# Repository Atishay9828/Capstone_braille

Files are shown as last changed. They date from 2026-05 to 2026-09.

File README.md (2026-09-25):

# Braillix

Braillix is a refreshable braille cell. It shows one braille character at a time,
and it changes that character on command. A single stepper motor moves all six
dots. The parts are 3D printed. The controller is an ESP32.

**Live mechanism simulator: https://mridulnegi2005.github.io/Capstone/**

The simulator runs the real cam profile. It reads the same numbers as the CAD
files. A motion that the printed cam cannot make is a motion the simulator cannot
show.

---

## Live demos

| Classroom frontend | Hardware mechanism |
|:--:|:--:|
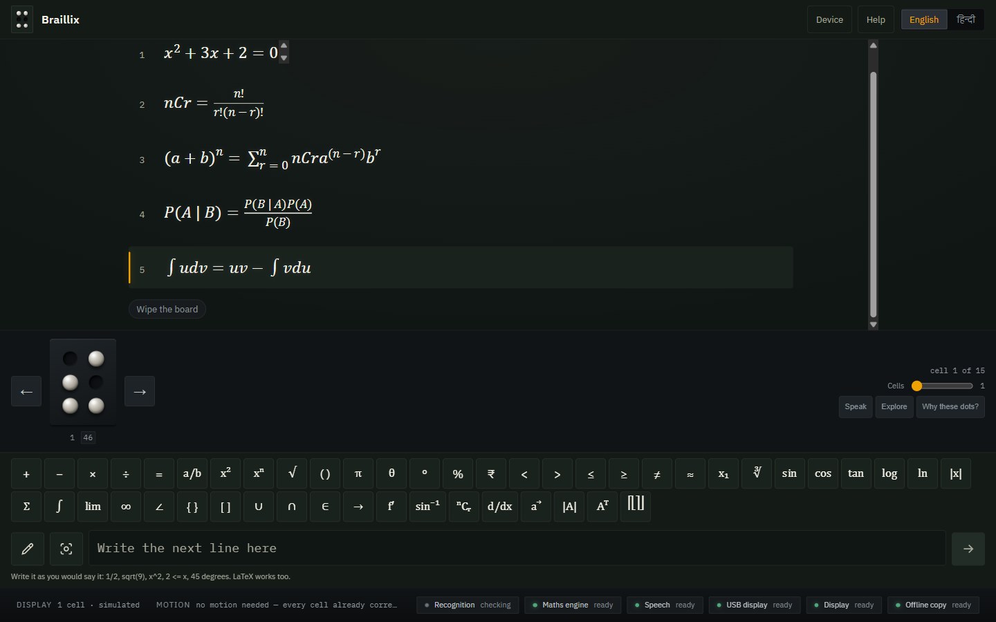
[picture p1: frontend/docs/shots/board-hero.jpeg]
Screenshot of the Braillix classroom frontend
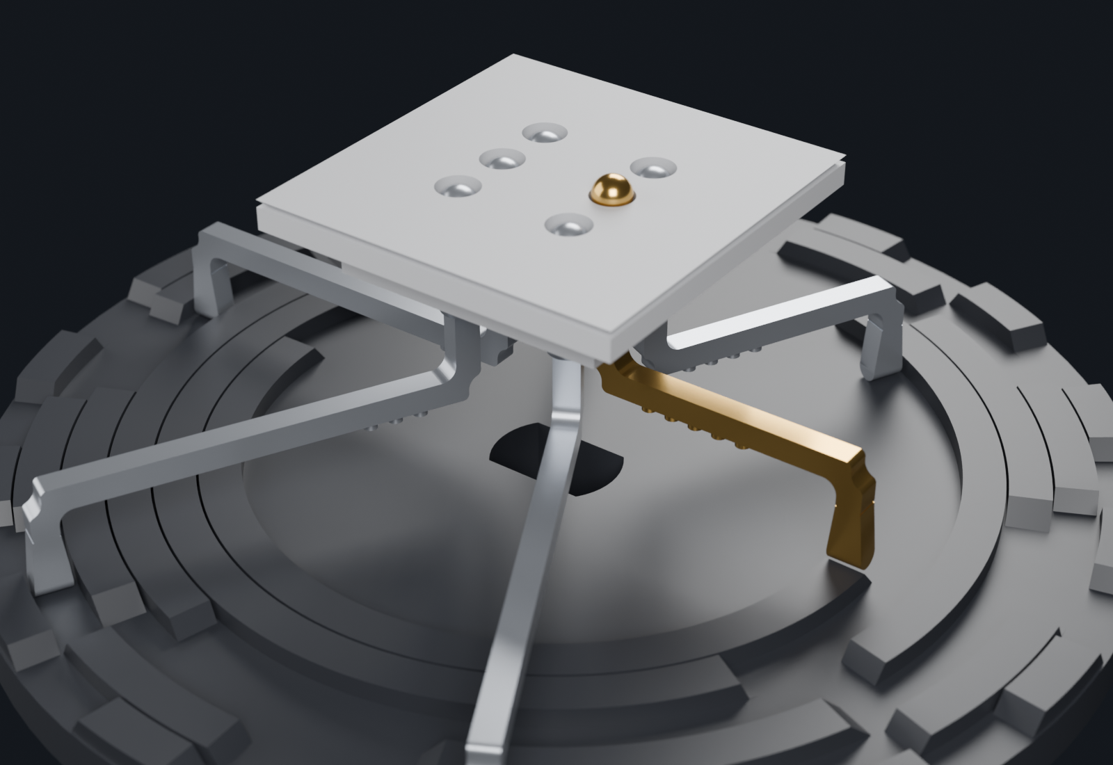
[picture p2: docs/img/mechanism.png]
3D render of the Braillix refreshable Braille cell mechanism
| [](https://braillix.vercel.app) | [](https://mridulnegi2005.github.io/Capstone/) |
| [Open the live classroom app](https://braillix.vercel.app) | [Open the live hardware simulator](https://mridulnegi2005.github.io/Capstone/) |

- **Backend API:** no public deployment is configured yet. Run it locally using the steps below;
  its interactive documentation is available at `http://localhost:8000/docs` while it is running.

The Vercel frontend and GitHub Pages simulator are separate deployments. The FastAPI service
currently runs locally and is not required by the frontend's main lesson flow.

## Software components

The software is split into a browser classroom app and a separately runnable Python API. Both
connect to the same Braillix goal—turning lesson content into Braille—but they do not currently
depend on each other for their main flows. The browser app performs its recognition and lesson
translation locally; the API exposes independent translation, OCR, and classroom-session
endpoints. The hardware and simulator live alongside them in this repository.

### Frontend classroom app (`frontend/`)

The React and TypeScript app provides a teacher-facing lesson blackboard. Teachers can type,
write, or photograph lesson content; inspect recognition and Braille readback; and send the
result to a simulator, a USB-connected pod, or Wi-Fi pods. English and Hindi text, mathematical
notation, speech, and multi-cell navigation are part of the browser app. Recognition and lesson
translation run on-device after the needed assets have been downloaded, so the basic lesson flow
does not require the Python API.

The frontend was imported with its commit history from
[SHV27/braillix](https://github.com/SHV27/braillix). It uses Node.js 20.19 or newer. To run it:

```bash
cd frontend
npm install
npm run fetch:model                 # one-time download of the math recognition model
node tools/fetch-tesseract-langs.mjs # one-time download of English and Hindi OCR data
npm run dev
```

Open the local URL printed by Vite (normally `http://localhost:5173`). For architecture,
feature details, optional pod simulation, and all frontend commands, see
[`frontend/README.md`](frontend/README.md) and [`frontend/ARCHITECTURE.md`](frontend/ARCHITECTURE.md).

### Backend API (`backend/`)

The Python service is built with FastAPI. It provides:

- Text and LaTeX mathematics translation to Braille, including converted cam-angle data.
- Image and PDF OCR endpoints for extracting lesson content and converting images to Braille.
- Classroom sessions with teacher and student WebSocket connections.
- A health endpoint and interactive API documentation.

The API creates its SQLite database (`braillix.db`) when it starts. Translation depends on the
system `liblouis` library and its tables. On Linux or macOS, the setup helper installs that
library, creates a virtual environment, and installs the Python dependencies:

```bash
bash scripts/setup.sh
source .venv/bin/activate
make dev
```

The service listens on `http://localhost:8000`; interactive documentation is at
[`/docs`](http://localhost:8000/docs). Main routes include `POST /translate`,
`POST /translate-math`, `POST /translate/cam-angles`, `POST /ocr/image`,
`POST /ocr/image-to-braille`, `POST /ocr/process-pdf`, `POST /classroom/sessions`, and the
`/classroom/teacher/{code}` and `/classroom/student/{code}` WebSocket routes. Starting without
`liblouis` is possible, but translation endpoints that need it report that the dependency is
unavailable. The setup helper currently supports Linux and macOS; on other systems install
`liblouis` and its tables manually before installing `requirements.txt` and running `make dev`.

### Hardware and simulator

The hardware path includes CAD, ESP32 firmware, the hardware abstraction layer, and the
mechanism simulator in `cad/`, `firmware/`, `hal/`, and `sim/`. Its original history is preserved
from [MridulNegi2005/Capstone](https://github.com/MridulNegi2005/Capstone). The browser app's
protocol and hardware setup are documented in [`frontend/docs/PROTOCOL.md`](frontend/docs/PROTOCOL.md)
and [`docs/`](docs/).

## What the device does

A braille character uses a cell of six dots. Each dot is up or down. Six dots give
64 different patterns. A reader identifies the character by touch.

Braillix raises and lowers those six dots on demand. A teacher sets a letter, and
a student reads it. The device then changes to the next letter.

Commercial refreshable braille displays cost between 2,000 and 6,000 US dollars.
They use piezoelectric actuators. Each dot needs its own actuator, and each
actuator is expensive. Braillix uses one motor and a shaped disc instead.

---

## How the mechanism works

The heart of the device is a **cam disc**. A cam is a shaped part that converts
rotation into linear movement.

### The disc

The disc carries six circular **tracks**. One track drives one dot. Each track has
high sections and low sections around its circumference.

The disc turns to 64 angular positions. Each position is one **slice**. Each slice
carries one of the 64 dot patterns.

### The follower

A **linkage** rests on each track. The linkage is a rigid crank. Its **foot** sits
on the track. Its other end carries the braille dot.

The mechanism

*The cam disc below, the six linkages above it, and the reading surface on top.
One linkage is gold. Its foot stands on a high section of its track, so its dot is
raised. The other five are down. The comb and the enclosure are left out of this
view.*

When the foot meets a high section, the linkage moves up. The dot rises above the
reading surface. When the foot meets a low section, the linkage moves down. The
dot becomes flush with the surface.

A return spring holds each linkage down against the disc.

### One motor for six dots

The six tracks turn together, because they are on one disc. One rotation of the
motor therefore sets all six dots at once. This removes the need for six
actuators.

The motor is a 28BYJ-48 stepper. It makes 4096 steps for each revolution. One
slice is 64 steps. The firmware turns the motor to the slice that holds the wanted
pattern.

### The guide

The foot rests on the disc. It does not clamp to it. A rotating disc therefore
drags the linkage sideways. A **comb** stops this. The comb is a fixed plate above
the disc. It has one closed pocket for each foot. The linkage slides up and down
in its pocket, and it cannot turn.

### Gray order

The slices do not carry the patterns in counting order. They carry them in **Gray
order**. In Gray order, two neighbour slices differ by exactly one bit. Only one
dot therefore moves for each step of the disc.

This gives two results. The dots do not flicker as much between letters. The motor
also lifts one dot at a time, not six, so it needs less torque.

The cam, the firmware and the simulator all share this order. All three must agree.

### Homing

A magnet sits in the underside of the disc. A hall sensor sits in the base plate
below it. The controller turns the disc until the sensor finds the magnet. That
angle is position zero. The controller counts steps from there.

---

## Repository layout

    Capstone/
    |
    +-- frontend/                    browser app and classroom interface
    |   +-- app/                      React + TypeScript lesson experience
    +-- backend/                     API, OCR, translation, and classroom services
    +-- hal/                          boundary between software and the display
    +-- cad/                        the design
    |   +-- scad/                   OpenSCAD source, 35 files. This IS the design.
    |   |   +-- mech_layout.scad        every shared dimension lives here
    |   |   +-- braille_cam.scad        the cam disc and its six tracks
    |   |   +-- linkage.scad            the six followers
    |   |   +-- linkage_comb.scad       the guide that stops them turning
    |   |   +-- outer_box.scad          the enclosure
    |   |   +-- base_plate.scad         holds the motor and the cam
    |   |   +-- mid_plate.scad          the motor shelf
    |   |   +-- top_plate.scad          the reading surface
    |   |   +-- dot_insert.scad         resin tile, six dot holes
    |   |   +-- esp32_pod_*.scad        housing for the controller
    |   +-- stl/                    meshes exported from scad/. Print these.
    |   +-- dxf/                    2D outlines
    |   +-- models/                 third-party component models
    |
    +-- firmware/                   what runs on the board
    |   +-- braille_cell/
    |   |   +-- braille_cell.ino        the current sketch
    |   +-- breadboard_test/            earlier bring-up sketch
    |   +-- braille_mapping.py          text to dot patterns
    |   +-- braille_converter.py
    |
    +-- sim/                        the simulator
    |   +-- 3d/
    |   |   +-- index.html              the page
    |   |   +-- app.js                  cam maths and animation
    |   |   +-- braillix.glb            the 3D model
    |   |   +-- vendor/                 a local copy of Three.js
    |   +-- braillix_params.json        the CAD-to-software bridge
    |   +-- extract_params.py           writes that file from the OpenSCAD source
    |
    +-- printing/                   getting parts made
    |   +-- orca/                       slicer profiles and the slice script
    |   +-- gcode_kobra_neo_checked/    released G-code
    |   +-- gcode_HOLD_*/               G-code held back, fit not yet proven
    |
    +-- docs/                       the engineering record, 32 notes
    |   +-- BRAILLE_READABILITY.md      measured against braille standards
    |   +-- MEASUREMENTS_NEEDED.md      every measurement, in plain words
    |   +-- BREADBOARD_STEP_BY_STEP.md  the wiring, one wire at a time
    |   +-- PRINT_DAY_MONDAY.md         the print procedure
    |   +-- MULTICELL_ARCHITECTURE.md   how to reach more than one cell
    |   +-- img/                        images used by this README
    |
    +-- tools/
    |   +-- validate_print_assets.py    checks meshes and G-code before release
    |
    +-- renders/                    images, and the scripts that make them
    +-- print_batch/                files prepared for a print shop
    +-- _archive/                   superseded work, kept for history

---

## Key files

### Design

The tree above names each part. Three of them need a word of explanation.

- **`cad/scad/mech_layout.scad`** is the single source of truth. Dot positions, the
  vertical stack, spring sizes and arm geometry live here, and every other file
  includes it. Change a number here, and every part follows. A dimension copied
  into a second file has caused real errors in this project, so nothing is copied.
- **`cad/scad/linkage.scad`** builds all six followers at once. Each one has a
  different arm length, because each foot sits on a different track.
- **`cad/scad/dot_insert.scad`** builds a small resin tile. It carries the six dot
  holes and the six spring pockets. Those features are too fine for an FDM printer,
  so they move out of the top plate and into one small part.

### Firmware

- **`firmware/braille_cell/braille_cell.ino`** is the current sketch. Type a letter
  into the Serial Monitor, and the cam turns to that letter.
- **`firmware/braille_mapping.py`** and **`braille_converter.py`** convert text to
  dot patterns on a computer.

### Simulator

- **`sim/3d/index.html`** and **`sim/3d/app.js`** are the simulator. The app reads
  the cam profile from the parameter file, and drives a 3D model with it.
- **`sim/braillix_params.json`** is the bridge between the CAD and the software.
  `sim/extract_params.py` writes it from the OpenSCAD source.

### Checks

- **`tools/validate_print_assets.py`** checks the printable files. It confirms that
  each mesh is closed, and that each G-code file matches the mesh it came from.
- **`printing/orca/slice_kobra_neo_checked.sh`** makes the G-code, and runs those
  checks.

### Documentation

The `docs/` directory holds the engineering record. These files are the most
useful:

- `BRAILLE_READABILITY.md` compares the design against braille standards.
- `MEASUREMENTS_NEEDED.md` lists every measurement, in plain words.
- `BREADBOARD_STEP_BY_STEP.md` gives the wiring, one wire at a time.
- `PRINT_DAY_MONDAY.md` gives the print procedure.
- `MULTICELL_ARCHITECTURE.md` studies how to reach more than one cell.

---

## Hardware

| Part | Detail |
|---|---|
| Controller | ESP32 DevKit, 30 pins, USB-C |
| Motor | 28BYJ-48 stepper, 5 V |
| Driver | ULN2003 module |
| Sensor | A3144 hall sensor, for homing |
| Power | 5 V supply, or the USB cable for a bench test |
| Printed parts | PETG for the enclosure, resin for the cam and the linkages |

---

## Build and run

### 1. Connect the electronics

Disconnect all power first. Then make these connections.

| From | To |
|---|---|
| ESP32 `GPIO 18` | ULN2003 `IN1` |
| ESP32 `GPIO 19` | ULN2003 `IN2` |
| ESP32 `GPIO 21` | ULN2003 `IN3` |
| ESP32 `GPIO 22` | ULN2003 `IN4` |
| ESP32 `GND` | ULN2003 `-` |
| ESP32 `5V` | ULN2003 `+` |
| Hall sensor `AO` | ESP32 `GPIO 34` |
| Hall sensor `VCC` | ESP32 `3V3` |
| Hall sensor `GND` | ESP32 `GND` |

Push the motor plug into the socket on the ULN2003 module. The plug fits one way.

Two warnings apply:

- The ground connection between the ESP32 and the driver is essential. Without it,
  the driver cannot read the control signals.
- Connect the hall sensor to `3V3`, not to `5V`. A 5 V signal on `GPIO 34` damages
  the ESP32.

An external 5 V supply is optional for a bench test. The USB cable gives enough
current for one motor. Do not connect an external supply and the USB cable to the
same rail.

### 2. Prepare the Arduino IDE

1. Install the Arduino IDE.
2. Open **File > Preferences**.
3. Add this URL to **Additional boards manager URLs**:
   `https://espressif.github.io/arduino-esp32/package_esp32_index.json`
4. Open **Tools > Board > Boards Manager**.
5. Search for `esp32`. Install the Espressif package.
6. Open **Tools > Manage Libraries**.
7. Search for `AccelStepper`. Install it.

### 3. Set the board options

Open the **Tools** menu. Set these options.

| Option | Value |
|---|---|
| Board | ESP32 Dev Module |
| Port | your COM port, or your `/dev/tty` port |
| Partition Scheme | **Huge APP (3MB No OTA/1MB SPIFFS)** |

The partition scheme matters. The default scheme gives the sketch 1.25 MB only.
The sketch needs more, because it includes the WiFi stack and the Bluetooth stack.
The `Huge APP` scheme gives 3 MB. The sketch does not use a filesystem, and it does
not use wireless upload, so this scheme costs nothing.

### 4. Flash the firmware

1. Open `firmware/braille_cell/braille_cell.ino`.
2. Press **Upload**.
3. Hold the **BOOT** button if the upload stops at `Connecting...`.
4. Open **Tools > Serial Monitor**.
5. Set the speed to **115200 baud**.
6. Set the line ending to **Newline**.

### 5. Drive the cell

The board searches for the homing magnet at start. It reports that no magnet is
present when no disc is on the shaft. This report is correct, and motion still
works.

Type a letter or a word, and press Enter. The motor turns to each character.

These commands are also available:

| Command | Action |
|---|---|
| `!spin` | Turn one full revolution |
| `!home` | Search for the homing magnet again |
| `!zero` | Set the current position to zero |
| `!hall` | Print the hall sensor reading |
| `!speed V A` | Set the maximum speed and the acceleration |
| `!gap MS` | Set the pause between letters |

The sketch also defines an access point name and password near the top of the
file. Change both values before any public demonstration.

### 6. Rebuild the printable files

Install OpenSCAD to change the design. Then export a part:

    openscad -o cad/stl/braille_cam.stl cad/scad/braille_cam.scad

Check every printable file:

    python tools/validate_print_assets.py --skip-gcode

### 6b. Rebuild the images in this file

Both pictures come from the CAD, not from a drawing program. Regenerate them after
any change to the mechanism, or they become wrong without any warning.

    cd renders
    openscad -D only=\"cam\"           -o /tmp/b/cam.stl           readme_mechanism.scad
    openscad -D only=\"linkages_down\" -o /tmp/b/linkages_down.stl readme_mechanism.scad
    openscad -D only=\"linkage_up\"    -o /tmp/b/linkage_up.stl    readme_mechanism.scad
    openscad -D only=\"insert\"        -o /tmp/b/insert.stl        readme_mechanism.scad

    blender -b -P blender_mechanism.py -- /tmp/b ../docs/img/mechanism.png 220 0 hero
    blender -b -P blender_mechanism.py -- /tmp/b ../docs/img/dot_raised.png 220 0 dot

The Blender step uses the GPU if one is present. It falls back to the processor
otherwise, and takes longer.

### 7. Run the simulator on your own machine

The simulator needs a web server. A browser blocks the 3D model over a `file://`
address.

    cd sim/3d
    python -m http.server 8777

Then open `http://localhost:8777/`.

---

## Status

The mechanism is under test. The motor, the driver, the wiring and the character
encoding all work. The cam and the linkages are in revision. The `docs/` directory
records each open item, and each measurement that supports it.

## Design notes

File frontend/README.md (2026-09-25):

# Braillix — the teacher's blackboard, on a blind child's fingers

A maths teacher who only knows WhatsApp opens one screen that **is** a blackboard: she writes
by hand, types, or photographs whatever she is teaching *right now* — full questions, worded
problems, worked steps — and it lands on her student's refreshable braille cells, live and
verified. In English and in Hindi. With no account, no server, no API key, and no network
needed after the first load.

**Live:** https://braillix.vercel.app

This repository is the **software half** of the Braillix capstone. The hardware half (the
ESP32 "brain pod" and the motorised "muscle cells") lives with the hardware team; this app
drives it over the wire protocol in `docs/PROTOCOL.md`, and is complete without it.

## The team

Braillix is a capstone project built by:

- **Shaurya Verma** — Software
- **Harshita** — Software
- **Aniket** — Software
- **Atishay** — Hardware
- **Mridul** — Hardware

## What it looks like

<p align="center">
  The blackboard on a laptop: a class 11–12 lesson standing as typeset chalk — the combinations formula, the whole binomial theorem, Bayes' theorem, integration by parts — with the amber marker on the current line, the braille cell below, and the full senior symbol vocabulary visible on the rail
</p>

<p align="center">
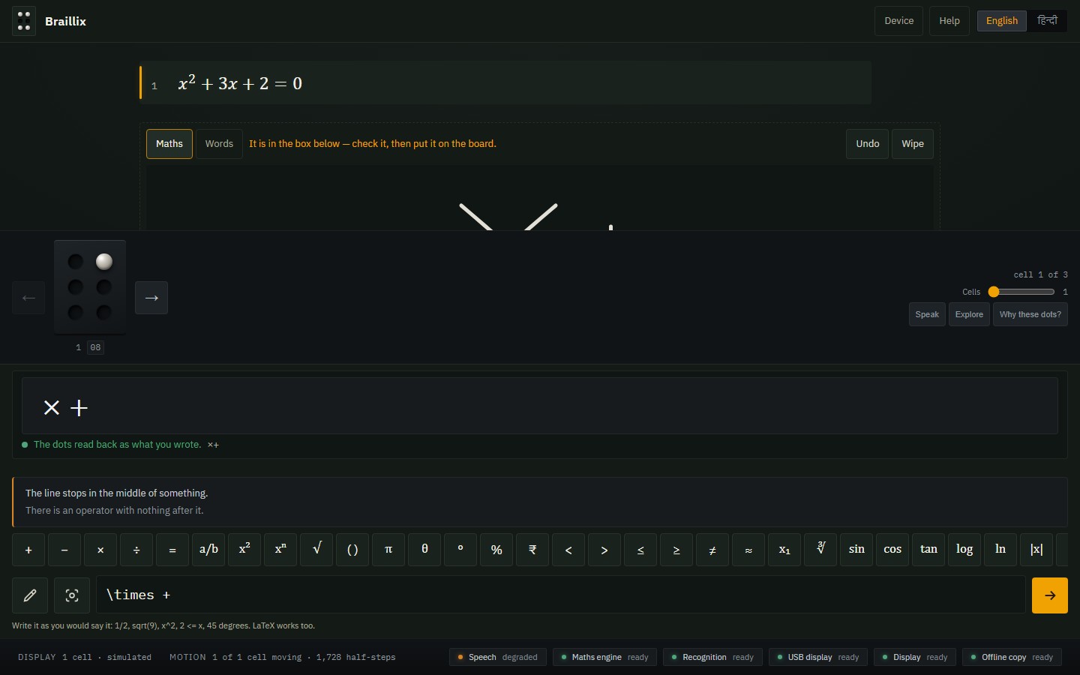
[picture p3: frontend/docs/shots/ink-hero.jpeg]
Writing on the board: hand-drawn chalk strokes on the board's next line, the recognised reading landed in the tray box with its print preview, the green braille verdict underneath, and an honest warning that the line stops mid-expression
  
</p>

<p align="center">
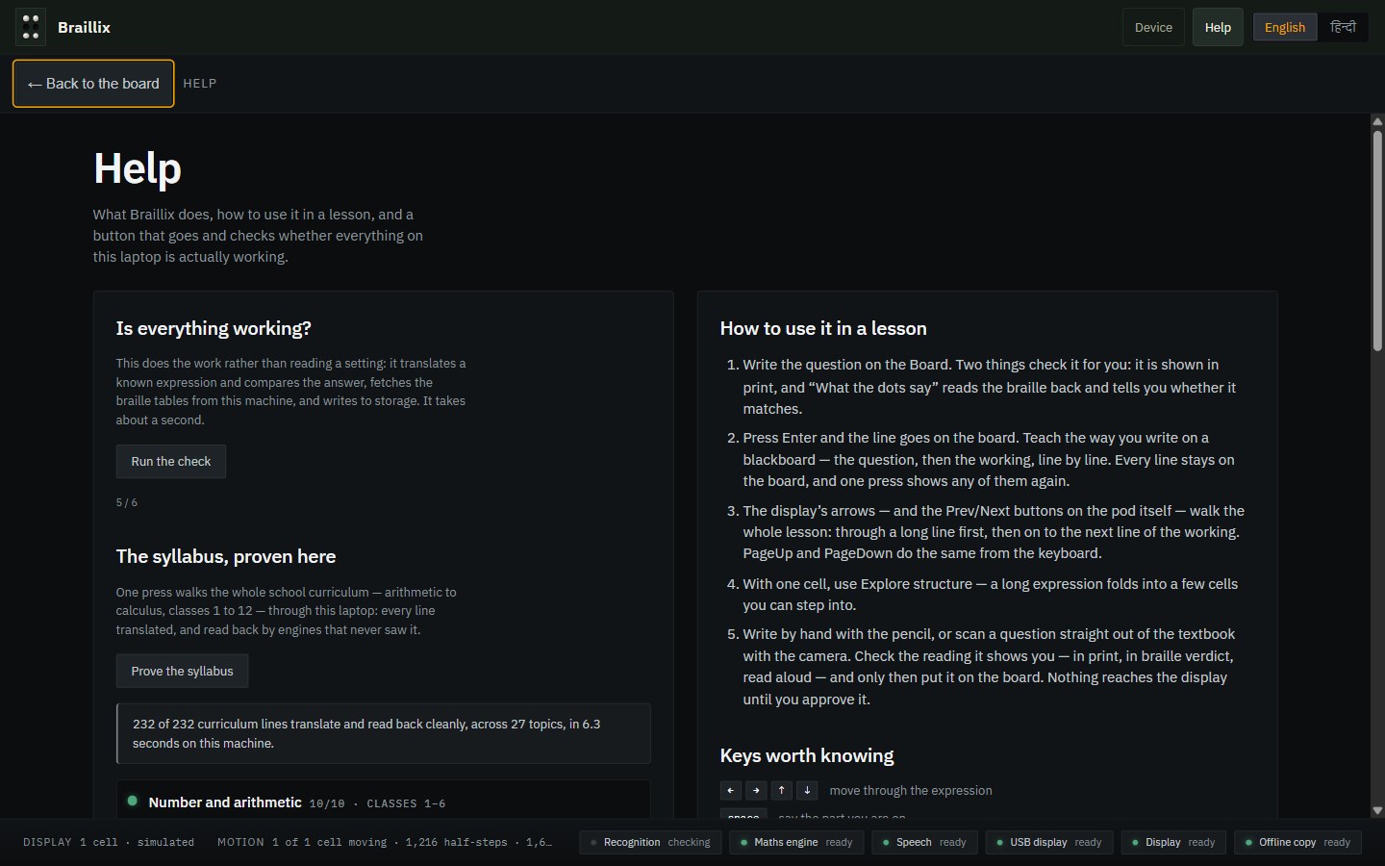
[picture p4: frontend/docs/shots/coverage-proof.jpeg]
The Help drawer proving the syllabus live on production: 232 of 232 curriculum lines translate and read back cleanly, across 27 topics, in about a second
  
</p>

The same blackboard, studio-grade at every size — a tablet held in class, and a phone held
sideways:

<p align="center">
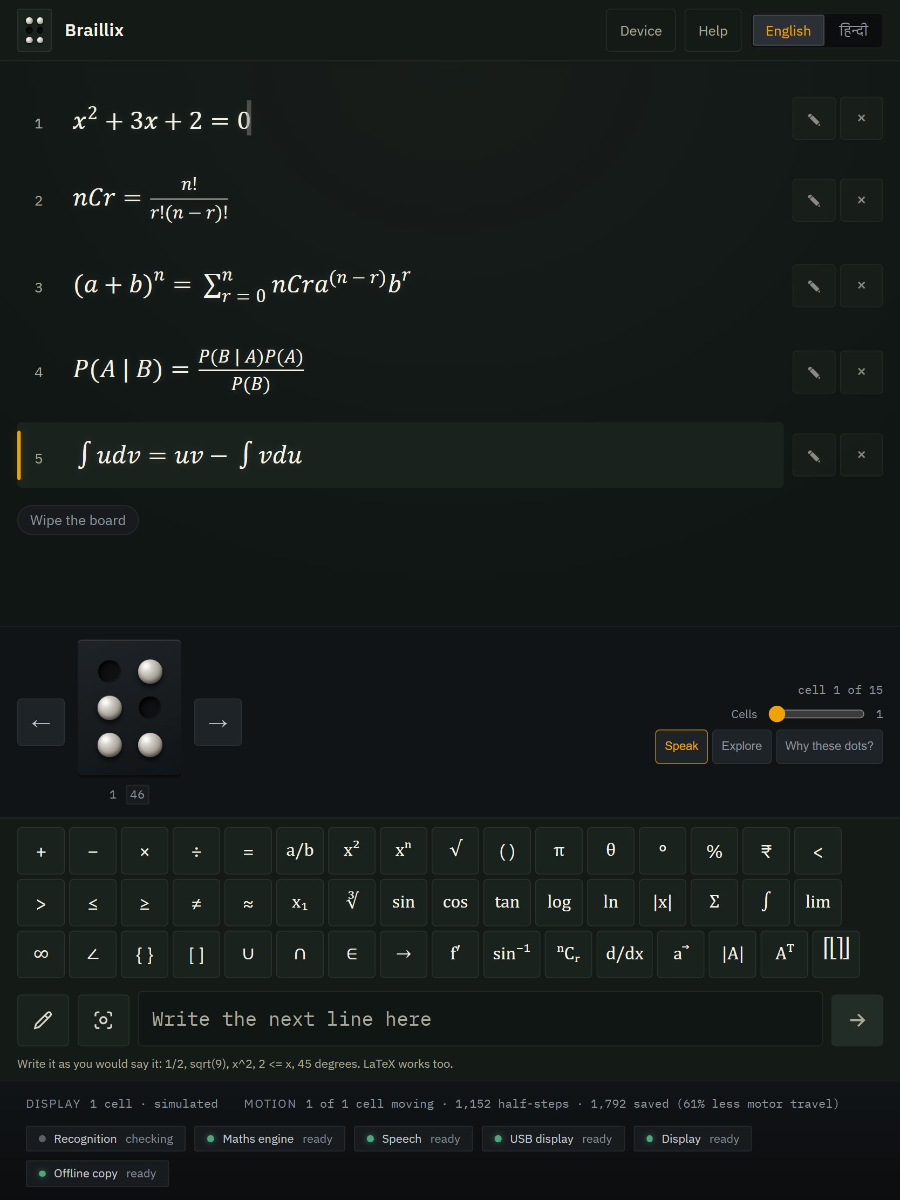
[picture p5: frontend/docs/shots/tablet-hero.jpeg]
The same senior lesson on a tablet: every line with its correct and rub-out tools always visible, all 48 symbol keys in three rows, the cells and the chalk tray
  
  &nbsp;
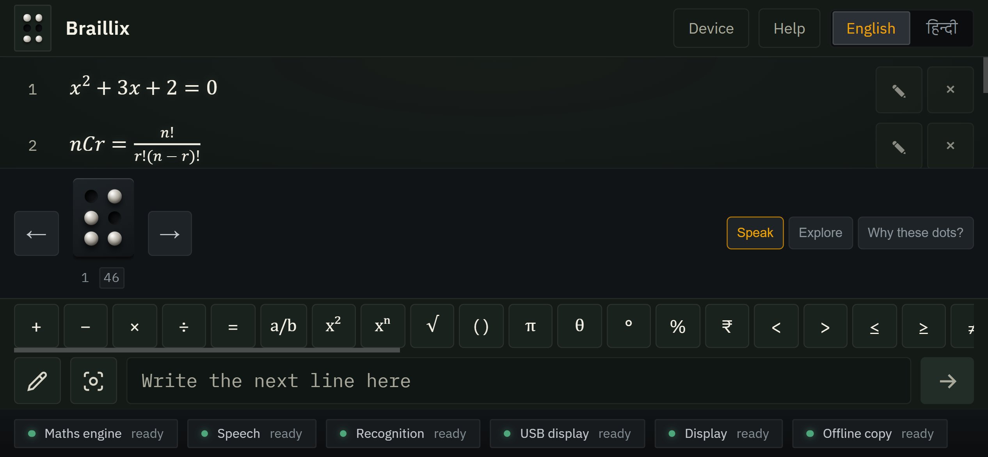
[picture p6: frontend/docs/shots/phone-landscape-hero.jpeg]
A phone held sideways: the board line, the cells, a sliding symbol rail and the writing hand all on one 390-pixel-tall screen
  
</p>

<p align="center">
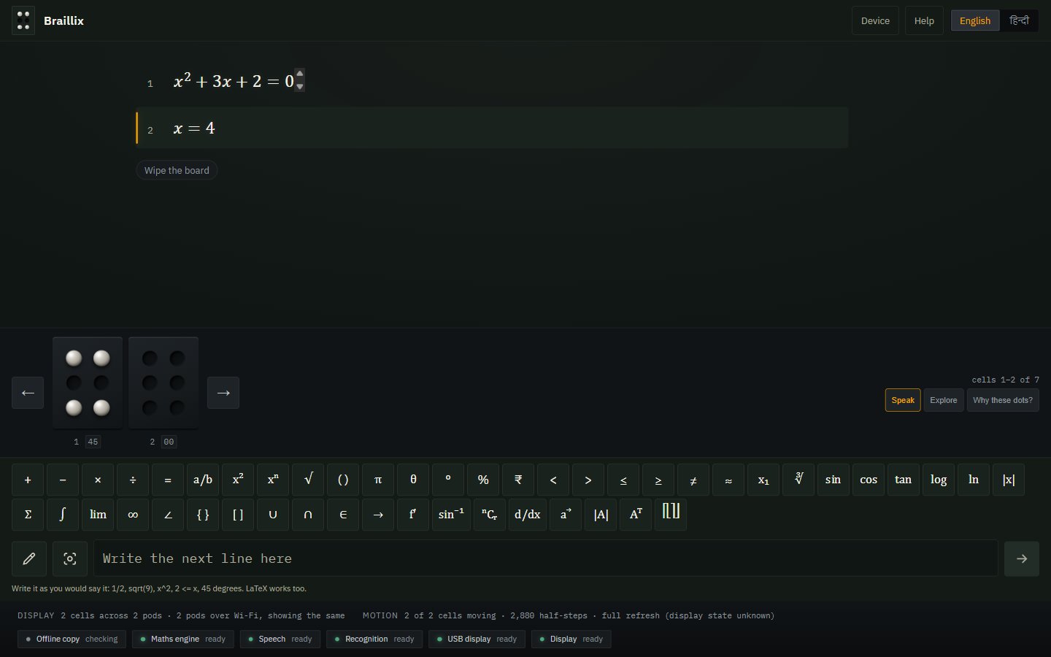
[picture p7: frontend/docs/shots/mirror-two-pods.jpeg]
Two Wi-Fi pods of different sizes mirroring one lesson — the status strip reads 2 cells across 2 pods, showing the same — each child reading the same expression under their own fingers
  
</p>

## What a lesson looks like

The whole app is one surface: the lesson standing on the board as typeset chalk, the cells
beneath it, and a chalk tray with every symbol a school line needs always on screen.

1. **Write it — like chalk.** Press the pencil and the board's next line becomes a writing
   surface. Write a step with a finger, stylus or mouse; the moment the hand pauses, the
   on-device recogniser reads it into the box below, with a print preview and a braille
   verdict to check. One press puts it on the board — and the teacher's own handwriting
   stays faintly behind the typeset line.
2. **Type it — like a message.** `2x + 3 = 11`, `sqrt(144)`, `1/2`, or a full Hindi question
   like `दो संख्याओं का योग 12 है` — Enter puts it on the board, on the cells, and in the
   room aloud. The print preview and the dots track every keystroke.
3. **Photograph it.** The camera grip reads an equation photo, or a full textbook question
   part by part — words by Tesseract (English + Hindi), maths by a 76 MB on-device formula
   model. Everything is read **on the laptop**, offline; nothing leaves the room.
4. **The walk.** The pod's own Prev/Next buttons — or PageUp/PageDown, or the on-screen
   arrows — walk the whole lesson: through the panes of a long line, then on to the next
   line. On a one-cell display that walk is seamless; on forty cells it is the same walk.

## Why every dot can be trusted

- **Nothing recognised reaches the display without a human.** A recognised line cannot even
  be *represented* as unconfirmed in the lesson store — the confirm gate is a TypeScript
  type, tested with `@ts-expect-error`.
- **Three independent proofs per expression:** Nemeth output from speech-rule-engine over
  temml MathML; golden vectors checked against published tables; and a hand-rolled
  **readback engine** that reconstructs the meaning from the dots alone — engines that never
  saw the input — shown to the teacher as "MATCHES WHAT YOU TYPED".
- **Uncertainty is said out loud.** Low-confidence scan parts are flagged "not sure — check
  this"; a failed translation falls back to literal braille and says so; every optional
  capability (recognition, speech, USB, pod, offline copy) publishes state · reason · fix.
- **The build refuses to ship blind.** `app/scripts/assert-assets.mjs` fails the build if
  the recognition model, the OCR language files, or the Nemeth tables are missing from the
  artifact — a dead button is a build error, not a discovery.
- **The syllabus is proven live, by anyone.** Help → "Prove the syllabus" walks all **232**
  curriculum lines through the real pipeline in the browser and reads each back — arithmetic
  to Bayes' theorem, classes 1–12, clean in about a second on the live site. The senior
  classes are covered at full depth: sets and functions (`A union B`, `f: A -> B`),
  combinatorics (`nCr = n!/(r!(n-r)!)`), the binomial theorem, inverse trigonometry, calculus
  from limits to differential equations (`int u dv = uv - int v du`), vectors and matrices,
  conditional probability (`P(A|B)`) — typed the way a teacher says them. The same evidence
  on paper is `docs/ACCURACY.md`, regenerated by `npm run accuracy`.
- **Many students, one lesson.** Several pods — of different sizes — can mirror the same
  cells, each child reading under their own fingers; or chain into one wide display. Proven
  against two protocol-accurate virtual pods (`docs/shots/mirror-two-pods.jpeg`).
- **Scanning is fast enough to teach with.** Both recognisers warm in the background at app
  start (the badge says so); press-to-result measured at ~1.25 s, where the cold path used
  to cost 64 s.

## The codes

Mathematics is **Nemeth** (the code Indian maths braille derives from); surrounding words
are **Grade-1 literary braille** in English and **Bharati Braille** for Hindi — one line can
carry all of them, with the boundary indicators emitted by the translator. Sources for both
tables are cited inline in `app/src/core/`.

## Hardware, discovered never assumed

The cell count comes from an I2C scan reported by the pod (`GET /chain`) — the software has
no literal cell count anywhere, including the simulator. One `Transport` interface, three
implementations (simulator, Web Serial USB, Wi-Fi pods), one shared conformance test suite.
`npm run pod` starts a zero-dependency virtual pod that speaks the entire protocol —
including nav buttons and multi-pod layout — so integration day starts from working, not
from hope. Cam bit order, cell direction and home position are runtime configuration with a
ten-second calibration screen, because the handoff document flags them as the likeliest
mismatch.

## Run it

```bash
npm install          # also copies SRE + tesseract assets into app/public
npm run fetch:model  # once: the 76 MB on-device formula model
node tools/fetch-tesseract-langs.mjs   # once: eng+hin word reading (3 MB)
npm run dev          # http://localhost:5173
npm run verify       # typecheck · lint · 727 unit tests · 101 e2e journeys + screenshots
npm run pod          # a virtual brain pod on :8080 — connect from the Device screen
```

Everything is self-hosted: fonts, Nemeth tables, both recognition engines. After the first
visit the service worker keeps the whole app working with the Wi-Fi unplugged.

## The evidence trail

- `docs/REPORT.md` — the full project report source: problem statement, stack, architecture,
  models, measured results, honest limitations
- `docs/ACCURACY.md` — all 232 curriculum lines with their braille and read-back verdicts
- `docs/PROTOCOL.md` — the hardware wire protocol, matched by `tools/virtual-pod`
- `ARCHITECTURE.md` — state authority, choke points, failure modes, stack lock
- `docs/shots/` — what it actually looks like, captured from the live site

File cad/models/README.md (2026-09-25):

# Third-party component models

Downloaded 2026-08-04. **Nothing here is our work.** Attribution and licences below.

```
kicad/          KiCad packages3D — CC-BY-SA 4.0
                28byj-48__5v_stepper_motor.glb — see below
```

## 28BYJ-48 stepper — **CC-BY, credit required**

**"28BYJ-48 5V Stepper Motor" by NandouTech**, from Sketchfab, licensed
**CC Attribution**. Downloaded manually by Mridul (Sketchfab requires an account).

Converted to `sim/3d/motor.glb` by `renders/export_motor_glb.py`, which strips a stray
`Cube` primitive and the eighteen mesh pieces making up five straight 2×2×20 fake leads,
then re-lands the model with the output shaft on the origin and the can bottom at z=0.
2,968 triangles.

> **This attribution must ship with the simulator.** CC-BY is otherwise a very easy
> licence to satisfy — no share-alike, commercial use fine.

## What is here and why

| File | Stands in for | Matches our part? |
|---|---|---|
| `TO-92_Inline` | A3144 hall sensor | ✅ exact — this is the package we desolder off the blue module |
| `PinSocket_1x15_P2.54mm_Vertical` | the two female header strips the DevKit plugs into | ✅ exact — 1×15, 2.54mm |
| `DIP-16_W7.62mm` | the ULN2003 chip on the driver board | ✅ exact package |
| `BarrelJack_CUI_PJ-063AH_Horizontal` | DC power inlet | ⚠️ **wrong body style** — this is PCB-mount horizontal, ours is an inline pigtail. Reference only. |

Both `.step` (solid CAD, for OpenSCAD/FreeCAD work) and `.wrl` (mesh, importable into
Blender → GLB for the simulator) are kept.

## Licence — read before shipping any of these

**CC-BY-SA 4.0** (`kicad/LICENSE_KiCad.md`). Two consequences for a public repo:

1. **Attribution required** — credit "KiCad Libraries, CC-BY-SA 4.0" wherever a derived
   asset ships.
2. **Share-alike is viral.** Any GLB derived from these carries CC-BY-SA too. It does not
   infect the rest of the repo, but that one asset file is encumbered forever.

KiCad waives article 3 for *electronic designs*. A Three.js visualisation is probably not
an electronic design, so **assume the waiver does not apply** and treat derived meshes as
plain CC-BY-SA.

## What could NOT be downloaded, and why

| Wanted | Blocker |
|---|---|
| **ESP32 DevKit V1** (Sketchfab, CC-BY, 1.6k tris) | needs a Sketchfab **account** — a human has to log in |
| **28BYJ-48 stepper** (Sketchfab, CC-BY, 3.7k tris) | same |
| ESP32-WROOM-32E module (Espressif's own KiCad repo) | repo has **no licence file** — `NOASSERTION`. Not safe to redistribute publicly. |
| Anything on **GrabCAD** | licence forbids passing files to third parties. A public repo is exactly that. |

To add the two Sketchfab models: log in, download the **glTF/GLB**, drop them in
`cad/models/sketchfab/`, and credit the authors here.

## Current state

The simulator does **not** use any of these yet — `sim/3d/electronics.js` is still fully
procedural. See `sim/3d/MODELS.md` for the reasoning. These are archived as reference and
as raw material if we decide the fidelity is worth the share-alike obligation.

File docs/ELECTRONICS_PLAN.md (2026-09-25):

# Braillix — Electronics Plan

**Written 2026-08-01. This is the electronics source of truth.**
Scope: **electronics only.** Mechanical/CAD issues are *flagged* here, never fixed here.

Written for a CS student with basic soldering. Every "why" is answered, because several
older documents in this repo tell you to build things you do not need.

---

# PART 0 — The short version

| Question | Answer |
|---|---|
| Do we need a custom PCB? | **No.** Not for one cell, not for two, not for multi-cell. |
| Do we need custom ICs? | **No.** The ATmega328P plan was over-engineering. |
| What do I own that works? | ESP32, 28BYJ-48 motor, ULN2003 driver, hall module, 5V adapter, **multimeter**. That is a complete single cell. |
| Is the jack polarity safe? | ✅ **YES — measured and confirmed correct, 2026-08-01.** |
| Do I own a soldering iron? | ❌ **No.** Buying guide in Part 9. **Do not buy a cheap plain iron.** |
| Can two cells work? | ✅ Yes, **direct-drive, no expander** — the ESP32 has the pins. See Part 10. |
| Does it scale past two? | ⏸️ Concept only. The four-wire dock still needs a per-cell 3.3V expander/regulator or level shifting, a measured carrier, and current-rated contacts. Part 5. |
| What breaks first at scale? | **Power, ~11 cells** — and only if they all move at once. Refresh sequentially and it goes away. |
| How do I stop joints breaking? | Heat-shrink + **anchor the wire**, not glue on the joint. **Hot glue, not epoxy** — the pin map will still change. Part 12. |
| What is the real blocker? | The one-cell breadboard is buildable; the enclosure harness, Hall calibration, and future four-wire dock are not yet physically/electrically validated. |

---

# PART 1 — Why there is no custom PCB, and never was a good reason for one

The old plan called for a "muscle board": a custom PCB carrying an **ATmega328P** per cell,
talking to the ESP32 over I²C.

**Kill it.** Three independent reasons:

1. **You cannot build it.** ATmega328P-AU is **TQFP-32 at 0.8mm pin pitch**. That is a
   reflow-oven or hot-air part. The project's own docs already concede it must be ordered
   pre-assembled — which directly contradicts doing everything yourselves.
2. **It solves a problem you do not have.** Its job was to let many cells share a bus. You
   have **one** cell. A single ESP32 drives it directly, today, with parts already in hand.
3. **When you *do* want many cells, an off-the-shelf module does the same job.** See Part 5.

> **Seven documents still reference the muscle board / KiCad / ATmega:**
> `DEMO_VS_PRODUCT.md`, `ELECTRONICS_BOM.md`, `MASTER_BOM.md`, `PRINT_CHECKLIST.md`,
> `SHOPPING_LIST.md`, `SOFTWARE_TEAM_README.md`, `WIRING_AND_ASSEMBLY.md`.
> Treat every one of those passages as **stale**. This file supersedes them.

### "Why did we need any of this at all?"

Walk the chain once and it stops feeling arbitrary:

```
An ESP32 pin can supply about 20mA at 3.3V.
A 28BYJ-48 motor coil wants about 200mA at 5V.
                       -> connect them directly and you destroy the ESP32 pin.

So you need something that takes a small signal and switches a big current.
That is ALL the ULN2003 is. Seven electronic switches in one chip.
You already own it, on the little blue board with four red LEDs.
```

That is the entire reason any driver exists. Nothing custom is involved.

---

# PART 2 — What lives where

```
   BRAIN POD  (one, ever)                MUSCLE CELL  (one per character)
   +---------------------------+         +---------------------------------+
   |  ESP32 DevKit             |         |  28BYJ-48 stepper motor         |
   |  3 nav buttons            |         |  Hall sensor (bare TO-92)       |
   |  DC power jack            |         |  ULN2003 driver board           |
   |  (multi-cell only:        |         |                                 |
   |   2x 4.7k I2C pull-ups,   |         |  (3+ cells: its OWN MCP23017,   |
   |    at the BRAIN end only) |         |   address set by 3 jumpers)     |
   +---------------------------+         +---------------------------------+
            |                                          ^
            +---- tomorrow: 8-wire direct harness ------+
              (IN1-IN4, Hall AO, Hall 3V3, motor 5V, common GND)

Future only: 4 wires (5V, GND, SDA, SCL) after each cell gets a compatible
3.3V expander/regulator or level shifting and a measured current-rated dock.
```

**Brain pod** = decides *what* to show. **Muscle cell** = makes it physically happen.
**There is only ever one brain.** Cells are identical, interchangeable and addressed — Part 5
shows how that holds up to 8, 16 or 64 of them without a single custom part.

---

# PART 3 — 🔴 Pin conflict, present in the code today

```
ASSEMBLY_BIBLE.md      GPIO21 -> ULN2003 IN3     GPIO22 -> ULN2003 IN4
SOFTWARE_TEAM_README   GPIO21 = I2C SDA          GPIO22 = I2C SCL
breadboard_test.ino    #define IN3 21            #define IN4 22
```

The motor and the I²C bus are assigned **the same two pins**.

- **Single cell:** harmless. No I²C exists yet. Do not change anything mid-demo.
- **The moment a second cell appears:** they collide, and neither works.

**Fix when multi-cell starts** — move the motor off the I²C pins:

| Signal | Now | Change to | Why |
|---|---|---|---|
| IN1 | 18 | 18 | fine |
| IN2 | 19 | 19 | fine |
| IN3 | **21** | **23** | frees SDA |
| IN4 | **22** | **27** | frees SCL |
| Hall AO | 34 | 34 | ADC1, input-only, fine |

⚠️ **Not GPIO 5.** An earlier revision of this table said `IN4 -> 5`. GPIO5 is a **strapping
pin** sampled at boot; a motor coil on it can stop the ESP32 starting. **27** is the correct
target and is what Part 10's pin map uses.

Requires editing `breadboard_test.ino` and re-flashing. **Do not do this before the demo.**

---

# PART 4 — Space: exactly one real constraint

| Location | Space | Verdict |
|---|---|---|
| Cell electronics pocket | **36 × 46 × 14mm** | ⚠️ **The only tight spot** |
| Pod interior | ~38mm spare headroom | Fine, wildly oversized |

**The problem:** a ULN2003 board with Dupont jumpers plugged in vertically stands **~20mm**.
The pocket is **14mm**. It does not fit.

**The fix:** cut the Dupont ends off and solder the wires **flat** against the board.
That drops it to ~12mm, leaving only about 2mm nominal spare before real tail/board measurements.
Temporary edge hot glue is acceptable after testing; final retention still needs a measured tray.

**Also flagged (CAD, not fixed here):** the *whole blue hall module* does not fit in the base
plate. Only the bare 3-legged sensor does, desoldered from the module, with three wires run
back. **Not needed for the breadboard demo.**

---

# PART 5 — Scaling to N cells

**You will build two. The architecture has to claim many more, and the claim has to be
true.** This part is what makes it true — and the honest answer is that it costs one ₹80
chip per brick and nothing else.

## The problem in one line

Each cell needs **4 motor lines + 1 sensor line = 5 wires back to the brain.**
Five wires per cell is a dead end: the ESP32 runs out of pins at ~4 cells, and no
snap-together brick can carry a cable that grows every time you add one.

## The fix: make the inter-brick cable a fixed width

```
   DEAD END — wires grow with cell count      SCALES — cable never changes
   +-------+                                 +-------+
   | BRAIN |=== 5 ===[C1]                    | BRAIN |
   |       |=== 5 ===[C2]                    +---+---+
   |       |=== 5 ===[C3]   ...                  | 4 wires: 5V  GND  SDA  SCL
   +-------+                                     |
     5N wires, N <= 4                     [C1]--[C2]--[C3]--[C4]-- ... daisy chain
                                           each brick taps the same 4
```

Every future brick could hang off the **same four wires** and be told apart by an address, but
the current CAD does not yet contain the required per-cell expander power/interface or a rated
flush connector. Treat the diagram below as architecture work, not a build instruction.

An MCP23017 powered at 5V does not guarantee a logic-high from ESP32 3.3V I2C. A real cell must
power the expander at 3.3V from a local regulator (while separately switching 5V motor power), or
use explicit level shifting. Prove that circuit and its enclosure fit before buying pogo hardware.

## 🔑 The decision that makes this real: one expander PER BRICK

An MCP23017 has 16 I/O. A cell needs 5. You *could* share one expander across 3 cells — but
then a brick is not self-contained, and "add a cell" means rewiring its neighbours.

**Give every brick its own expander instead.** Wasteful on paper (5 of 16 pins used),
correct in practice:

| | Shared expander (3 cells each) | **One per brick** ✅ |
|---|---|---|
| Bricks identical? | No | **Yes — every cell is the same object** |
| Adding a cell | rewire neighbours | **plug in, set 3 jumpers** |
| Max cells / bus | 24 | 8 |
| Cost per cell | ~₹27 | ~₹80 |

₹53 per cell buys a genuinely modular brick. Take it.

**Address = position.** The MCP23017's A2/A1/A0 pins select one of 8 addresses (0x20–0x27).
Three jumpers or a tiny DIP switch on each brick. Firmware scans the bus at boot and
**discovers how many cells are attached** — no recompile to change the display length.

## Use MCP23017. Do NOT use PCF8574.

| | MCP23017 | PCF8574 |
|---|---|---|
| I/O | 16 | 8 |
| Output type | **true push-pull** | quasi-bidirectional, **weak high side** |
| Drives a ULN2003 input? | **Yes** | ⚠️ **Marginal — avoid** |
| Package | DIP-28, hand-solderable | DIP-16 |
| Addresses | 8 (0x20–0x27) | 8 |

**Why this matters:** a ULN2003 input needs a couple of mA *sourced into* it. The PCF8574's
high state is a weak pull-up of roughly 100µA. It looks like it should work, and it will
half-work — the worst possible failure mode. MCP23017 sources properly.

## The ceiling, stated honestly

| Cells | What you need | Extra cost |
|---|---|---|
| **1–2** | Direct GPIO. No expander at all. *(Part 10)* | ₹0 |
| **3–8** | 1× MCP23017 per brick, one I²C bus | ~₹80/cell |
| **9–16** | Second I²C bus — **the ESP32 has two controllers** | ₹0 more |
| **17–64** | TCA9548A I²C multiplexer, 8 buses | ~₹120 once |

**Nothing custom appears at any tier.** No PCB, no ATmega, no SMD.

## What actually breaks first — and it isn't addressing

⚠️ **Power, at about 11 cells** — but only if you move them all at once:

```
5V 3A supply  =  3000mA
  - ESP32                    250mA
  = 2750mA  /  250mA per energised motor  =  11 motors simultaneously
```

**Refresh the cells one at a time and this limit disappears entirely** — a cell draws current
only while it is turning, ~0.4s. A 20-cell line refreshing sequentially never exceeds two
motors' worth. This is also why *"de-energise the coils when idle"* is an architectural rule,
not a nicety: hold all 20 energised and you need a 60W supply to display static text.

## Three rules that must be locked in now

These are cheap to honour today and expensive to retrofit:

1. 🔴 **I²C pull-ups live at the BRAIN end only — 2× 4.7kΩ, once, ever.**
   Putting them in every brick is the classic mistake: 8 bricks × 4.7k in parallel = **590Ω**,
   which exceeds what an I²C device can sink. The bus stops working and the cause is invisible.
2. **Hall sensors move from AO to DO.** An expander has **no ADC**. Single-cell uses the analog
   pin; multi-cell must use the module's digital output and its trimmer pot has to be
   **calibrated per cell**. Budget for that — it's a knob-turning session, not a redesign.
3. **Keep the bus short and slow-able.** I²C tolerates ~400pF total. Short jumpers across 8
   bricks are fine; if a long chain goes flaky, drop the clock to 100kHz before suspecting
   anything else.

## What this means for the two boards you're building

Build the breadboard demo on **direct GPIO** — it's unblocked today and needs no expander.
Then build **both muscle boards with the expander architecture anyway.** The two cells you
physically make are then not a two-cell hack; they are cells 1 and 2 of an N-cell bus, and
adding cell 3 is a purchase, not a redesign. **That is what makes the claim demonstrable to
the panel** — you can point at the address jumpers.

**Total custom silicon required: zero. Total SMD soldering: zero.**

---

# PART 6 — What to actually do, in order

### 1. ✅ Jack polarity — DONE, 2026-08-01

Measured with a multimeter and **confirmed correct: red = positive, black = ground.**
The single largest risk to the ESP32 is now retired. Mark the positive wire physically
(nail polish, marker, a tag) so it can never be confused later.

### 2. Buy a soldering iron — see Part 9

You do **not** own one. Nothing in the build is blocked by this yet, because the
breadboard demo needs no soldering. **Part 9 explains exactly what to buy and why the
₹200 irons are a trap.**

### 3. Build the breadboard circuit — **the actual blocker**

No soldering. Dupont jumpers only. Full wiring in `docs/ASSEMBLY_BIBLE.md`.

```
[5V adapter] --+--> breadboard 5V rail  --> ULN2003 (+)
               +--> breadboard GND rail --> ULN2003 (-)

ESP32 (powered by USB from the laptop)
  GND    --> breadboard GND rail       <-- COMMON GROUND. Without it the hall reads garbage.
  3V3    --> Hall VCC
  GND    --> Hall GND
  GPIO34 <-- Hall AO
  GPIO18 --> ULN2003 IN1
  GPIO19 --> ULN2003 IN2
  GPIO21 --> ULN2003 IN3
  GPIO22 --> ULN2003 IN4
```

Two rules that protect the hardware:

1. **Hall sensor VCC goes to 3V3, never 5V.** ESP32 GPIOs are not 5V tolerant.
2. **Never feed the adapter into ESP32 `VIN` while USB is plugged into the laptop.**
   Motor from the adapter, ESP32 from USB, **grounds joined only.**

### 4. Flash and confirm

`firmware/breadboard_test/breadboard_test.ino` → motor turns, hall finds home, dashboard
appears on your phone. **That is a legitimate, demonstrable result** — and it is the same
circuit the first real cell uses, so none of it is throwaway.

---

# PART 7 — Known electronics defect, not yet fixed

**`breadboard_test.ino` targets the wrong step position.**

```c
long targetStep = (long)pos * STEPS_PER_REV / 64;        // lands mid-RAMP
long targetStep = (long)pos * STEPS_PER_REV / 64 + 32;   // lands mid-DWELL
```

The cam's ramps are centred on slice boundaries, so `pos × 64` stops the follower **on the
slope** instead of on the flat. Verified numerically: at position 0 all six dots sit at
factor 0.5 — half-raised, unreadable.

**Not applied yet** because it is tied to a mechanical re-derivation happening in the CAD
fork. Recorded here so that if the bench shows half-raised dots, nobody hunts for a
mechanical cause that does not exist.

---

# PART 8 — Shopping, electronics only

✅ **Already owned:** multimeter, ESP32, motor, ULN2003, hall module, 5V adapter, DC pigtail.

| Item | Why | ₹ |
|---|---|---|
| **Soldering station** (see Part 9) | 🔴 The one real gap. **Temperature-controlled, not a plain iron.** | ~1,300 |
| **Solder, 0.8mm 60/40 leaded, rosin core** | Every joint in this project | ~150 |
| **Breadboard** | The entire demo runs on it | ~100 |
| **Wire strippers** | Prepping wire ends | ~200 |
| **USB-C data cable** | To flash the ESP32. Charge-only cables look identical and fail silently — **test yours first.** | ~150 |
| **Heat-shrink assortment** | Insulating every splice | ~100 |
| **Desoldering wick** | Fixing bridges; lifting the hall sensor off its module | ~80 |
| **Helping-hands / third hand** | Not optional in practice — you cannot hold iron, solder and two wires with two hands | ~200 |

**~₹2,280**, or ~₹2,130 if your existing USB-C cable carries data.

**Not needed:** any driver IC (you own it), resistors, capacitors, flyback diodes (inside the
ULN2003), level shifters, crystals, and **any custom PCB**.

---

# PART 9 — Buying a soldering iron, explained

You said the options confused you. They are confusing, and **most of what an electronics shop
will sell you for ₹200 is close to useless for this work.** Here is the whole decision.

## The only choice that really matters

> ### Buy a temperature-CONTROLLED soldering STATION. Not a plain "pencil" iron.

| | Plain pencil iron ₹150–300 | **Soldering station ₹1,200–1,800** |
|---|---|---|
| Temperature | Uncontrolled — climbs until it stops | **You set it. It holds it.** |
| In practice | Too hot: burns flux instantly, oxidises the tip black, lifts pads | Correct heat, joints flow properly |
| Tip life | Days | Months |
| Stand | Usually none | Included |
| Beginner result | Blames themselves for "being bad at soldering" | Actually learns |

**Why uncontrolled irons ruin beginners:** solder needs the *joint* at ~250°C. A plain iron
free-runs to 400°C+, which burns the flux off before it can clean the metal. Solder then balls
up and refuses to stick — and it looks exactly like bad technique. It isn't. It's the tool.

**This is the single highest-value ₹1,000 in the whole project.**

## What to search for

> **"60W soldering station temperature controlled 936"**

The `936` design is an old Hakko layout that everyone clones. Common brands in India: **Soldron,
Yihua, Aptech**. They are all much the same. Roughly **₹1,200–1,800**.

## Reading the spec sheet

| Spec | Get | Why |
|---|---|---|
| **Temperature control** | **Yes — non-negotiable** | The entire reason to buy a station |
| **Wattage** | **60W** | Not "how hot" — how *fast it recovers* after touching cold metal. 60W recovers quickly. |
| **Heating element** | **Ceramic** | Faster and more accurate than nichrome |
| **Tip shape** | **Chisel ~2.4mm** ("D24"/"D-type") | More contact area = faster heat transfer. **A fine conical tip is the classic beginner mistake** — it looks precise and transfers heat poorly. |
| **Temp range** | 200–450°C | You'll use 320–350°C |
| **Stand + sponge** | Included | Ignore, buy brass wool if you can |

## Settings for this project

```
Solder      0.8mm  60/40 LEADED, rosin core     <- leaded, deliberately
Temperature 330 C  for everything here
Tip         2.4mm chisel
```

**Use leaded 60/40, not lead-free.** Lead-free melts ~40°C hotter, wets far worse, and is
genuinely harder for a first-timer. Leaded is legal for hobby/education use. **Wash your hands
afterwards, don't eat at the bench**, and that is the whole safety story.

**Ventilate.** The smoke is burning flux, not lead — it is an irritant, not a heavy-metal
vapour. Open a window; don't hunch over it.

## What NOT to buy

- ❌ **A plain 25W/35W pencil iron.** The trap this section exists to prevent.
- ❌ **A "soldering gun"** (pistol-shaped, instant heat) — for wiring, far too crude here.
- ❌ **TS100 / Pinecil USB-C smart irons** (₹3,000–5,000) — genuinely excellent, but they need a
  good USB-C PD supply and cost triple. Overkill for this build.
- ❌ **Fine conical tips.** Get the chisel.

---

# PART 10 — The two-cell product

## What it looks like

```
   +--------------+   +--------------+   +--------------+
   |  BRAIN POD   |   |    CELL 1    |   |    CELL 2    |
   |              |   |              |   |              |
   |   ESP32      |   |   . .        |   |   . .        |   <- 6 braille dots each
   |   3 buttons  |   |   . .        |   |   . .        |
   |   DC jack    |   |   . .        |   |   . .        |
   |              |   |  motor+cam   |   |  motor+cam   |
   +--------------+   +--------------+   +--------------+
        68mm              68mm               68mm          = 204mm

   Shows TWO characters at once. Magnets hold the bricks together.
   Wires run between them through the existing wire-exit holes.
```

**Two cells = two characters.** With the nav buttons you scroll a longer word through them.

## 🔑 The key decision: no expander, no I²C, no extra parts

Part 5 describes an MCP23017 expander per brick. **That earns its place from 3 cells up.
At two cells it is unnecessary** — the ESP32 has enough pins to drive both directly:

```
safe output pins available : 15
two cells + nav need       : 11
spare                      : 4
```

So **cell 2 costs you nothing but wire.** No new chips, no I²C, no addresses, no pull-ups.

## Pin map — designed so adding cell 2 never touches cell 1

| Signal | GPIO | Notes |
|---|---|---|
| **Cell 1** IN1 / IN2 / IN3 / IN4 | 18, 19, **23**, **27** | 21/22 freed — see the Part 3 conflict |
| **Cell 1** hall AO | 34 | input-only, ADC1 |
| **Cell 2** IN1 / IN2 / IN3 / IN4 | 13, 14, 26, 33 | all safe, no strapping pins |
| **Cell 2** hall AO | 35 | input-only, ADC1 |
| Nav Prev / Select / Next | 32, 25, 17 | `INPUT_PULLUP`, active-LOW |
| *(reserved)* I²C SDA / SCL | 21, 22 | kept free for a 3rd+ cell later |

⚠️ **Avoid GPIO 0, 2, 5, 12, 15** entirely — they are *strapping pins* read at boot. A motor
coil wired to one can stop the ESP32 booting. That is why cell 1 moves off 21/22 to 23/27.

## Power

```
5V 3A adapter
   |
   +--> ESP32        ~250mA peak (WiFi)
   +--> Cell 1 motor ~250mA while energised
   +--> Cell 2 motor ~250mA while energised
                     ------
                     ~750mA of 3000mA available   -> plenty
```

⚠️ **De-energise the motors when idle.** A stepper holding position draws full current and gets
warm for no benefit. The firmware should release the coils after each move.

---

# PART 11 — Soldering, from zero

Written assuming you have never made a reliable joint. Nothing here needs a steady surgeon's
hand — soldering is about **heat and cleanliness**, not dexterity.

## The one idea that makes soldering work

> ### Heat the JOINT. Let the JOINT melt the solder.
> **Never melt solder on the iron and carry it over.**

Solder flows *toward heat* and sticks only to metal that is hot enough and chemically clean.
Melting solder on the tip and dabbing it on gives you a **cold joint** — it looks attached,
conducts badly, and fails weeks later. This is the mistake essentially every beginner makes.

```
   RIGHT                                WRONG
   1. tip touches BOTH parts            1. melt blob on tip
   2. wait ~2 seconds                   2. dab blob onto parts
   3. feed solder INTO the joint        3. it sits there like grey chewing gum
   4. it flows and wets instantly
   5. remove solder, then iron
```

**A good joint is shiny and concave**, like a tiny volcano hugging the wire.
**A bad joint is dull, round and blobby** — it beaded up instead of wetting.

## Before your first joint

1. **Set 330°C.** Wait for it to reach temperature.
2. **Tin the tip:** melt a little solder onto it, wipe on brass wool or damp sponge. It should be
   mirror-silver. A black tip transfers almost no heat — re-tin it.
3. **Re-tin every few joints, and always before switching off.** A tip left bare oxidises and dies.

## Job 1 — DC jack to header pins *(do this first, it's the easiest)*

Your jack is an **inline pigtail**: a barrel socket with two bare wire ends. Bare wire does not
sit in a breadboard.

```
   [barrel socket]===red wire=====> solder to pin 1 --+
                  ===black wire===> solder to pin 2 --+--> 2-pin male header
                                                            plugs into breadboard
```

1. Strip ~4mm of insulation from each wire.
2. **Tin each wire:** heat it, feed solder in, until the strands turn silver and hold together.
3. **Tin the two header pins** the same way.
4. Hold the wire against the pin, touch the iron to both, and they fuse in about a second —
   both surfaces are already tinned. This is called a **tack joint**.
5. **Slide heat-shrink over each joint before you solder the second one.** Everyone forgets.
   Shrink it with the side of the iron barrel or a lighter held well away.
6. ⚠️ **Keep red and black clearly distinguishable.** Polarity is confirmed correct — do not
   lose that information at the connector.

**Nothing is powered while you do this.** Ideal first job.

## Job 2 — ULN2003 wires flat *(only when you assemble cell 1)*

**Why:** with Dupont jumpers plugged in vertically the board is ~20mm tall. The pocket is
**14mm**. Soldered flat it is ~12mm, leaving only nominal tolerance.

1. Cut the Dupont connector off six wires — IN1, IN2, IN3, IN4, `+`, `−`.
2. Strip and tin each.
3. Feed each wire through its hole from the **top**, bend it flat along the board, solder underneath.
4. Snip the excess.
5. ⚠️ **Check for bridges** — solder accidentally joining two adjacent pads. Hold it to the light.
   A bridge between IN1 and IN2 means the motor will buzz and not turn. Fix with desoldering wick.

## Job 3 — Hall sensor off its module *(cell assembly, later)*

The blue module does not fit inside the machine. Only the little black 3-legged sensor does.

1. Note **which leg is which** before removing anything. Photograph it.
2. Heat each leg and lift with tweezers, or use desoldering wick to clear the pads.
3. Solder three wires to the legs, **heat-shrink each individually** — they are ~1.27mm apart
   and a short between VCC and GND is a dead sensor.
4. **This is the fiddliest job in the project.** Leave it until you're comfortable.

*(Where it physically mounts is a **CAD** question — flagged, not solved here.)*

## Job 4 — Adding cell 2

Cell 1 stays untouched. All you do is add wires.

**The power spine** — one source feeding three places:

```
        jack red (+)                    jack black (-)
             |                               |
        +----+----+                     +----+----+
        |    |    |                     |    |    |
      ESP32 C1   C2                   ESP32 C1   C2
```

1. Strip a 10mm window in the middle of a wire (don't cut it) and wrap the branch wire through it.
2. Solder, then heat-shrink. This is a **Western Union splice** and it is far stronger than
   twisting.
3. Alternative if you'd rather not splice: a **2-way screw terminal block**, ~₹20, no soldering.
4. Run cell 2's four control wires to GPIO **13, 14, 26, 33** and its hall to **35**.

**Firmware:** add a second `AccelStepper` object on the new pins. The braille encoding, homing
and dashboard all work unchanged.

## When it goes wrong

| Symptom | Cause | Fix |
|---|---|---|
| Solder balls up, won't stick | Joint not hot enough, or tip oxidised | Re-tin the tip; heat the joint longer |
| Joint dull and lumpy | Cold joint — moved before it set | Reheat until it flows shiny |
| Iron won't melt solder | Black oxidised tip | Re-tin. If it won't take solder, replace the tip |
| Motor buzzes, doesn't turn | Solder bridge between IN pins, **or** two coil wires swapped | Inspect for bridges; try swapping IN2/IN3 |
| Wire pulls straight out | Cold joint | Redo it. A good joint won't pull off. |
| Everything worked, now nothing | Check the **common ground** first | It is almost always the ground |

## Practice first

**Do not let the ESP32 be your first ever joint.** Solder a few scrap wires together, cut them
open, look at the cross-section. Twenty minutes of practice with ₹5 of wire saves a ₹350 board.

---

# PART 12 — Making joints permanent (what to put on after soldering)

## First, the thing almost everyone gets wrong

> **Solder joints don't fail because the solder breaks.
> They fail because the WIRE flexes right where it enters the joint.**

The solder is stiff; the wire is soft. Every wiggle concentrates at that exact boundary until
the copper work-hardens and snaps — often *inside* the insulation, so it looks perfect and
reads open on the multimeter.

⚠️ **So gluing the joint itself doesn't fix it.** A hard blob only moves the flex point 2mm
along and can make it *worse*. **You have to stop the wire from moving** — anchor it 5–10mm
away so the joint never sees the force. That's what "strain relief" means, and it does more
than any adhesive.

## Do these in order

| Order | What | Why |
|---|---|---|
| **1** | **Heat-shrink tubing** over every joint | ⭐ Insulates *and* stiffens the transition. Slide it on **before** you solder — everyone forgets this once. |
| **2** | **Anchor the cable** — zip tie, clamp, or a dab of hot glue on the wire *away* from the joint | This is the actual fix. The joint stops flexing. |
| **3** | *Only then* consider a coating | Everything below is a bonus, not a substitute |

## The coatings, honestly compared

| Option | Hardness | Reworkable? | Verdict for Braillix |
|---|---|---|---|
| **Hot glue** | soft, rubbery | ✅ peels off | ⭐ **Use this.** Cheap, instant, great strain relief, and you *will* need to undo things. Softens ~70°C — irrelevant here. |
| **Neutral-cure RTV silicone** | flexible | ✅ mostly | ⭐ Best vibration resistance. ⚠️ Must be **neutral-cure** — see warning below. |
| **2-part epoxy** | rock hard | ❌ **never** | Only for the final, fully-tested build. Hard *and brittle* — it transfers shock to the joint instead of absorbing it. |
| **Conformal coating** (acrylic spray) | thin film | ✅ with thinner | Protects against moisture/oxidation. Adds **no** mechanical strength. Not needed indoors. |
| **UV resin** (you have a resin printer) | hard, brittle | ❌ | Tempting since it's on hand — but it won't cure in shadow under a wire, leaving sticky uncured resin. Skip it. |
| **Nail polish** | thin | ✅ acetone | Genuinely fine for locking a *screw* or marking polarity. Not a structural adhesive. |

### 🔴 Two warnings worth more than the rest of this section

1. **Never use acetic-cure silicone** (the hardware-store bathroom kind that smells of
   vinegar). It releases **acetic acid** as it cures, which corrodes copper and eats your
   joints over months. The tube must say **neutral cure** / oxime / alkoxy.
2. **Do not epoxy anything until the whole circuit is verified working.** Epoxy on ESP32
   header pins means the board is scrap if the pin map changes — and *your pin map is going
   to change* (Part 3's conflict fix, and the expander migration in Part 5). **Hot glue until
   the design is frozen.**

## Where each one belongs on this build

```
DC jack wires ---------> heat-shrink + hot glue blob at the strain point
ULN2003 flat wires ----> heat-shrink; hot glue ONLY after the pocket fit is confirmed
Hall sensor 3 wires ---> heat-shrink; the TO-92 itself gets epoxied into the CAD pocket
Inter-brick cable -----> connector, not glue -- it MUST come apart (Part 5 is modular)
Nav buttons -----------> hot glue, so the pod can be opened
```

⚠️ **Never glue the inter-brick connection.** The entire scaling argument in Part 5 depends on
bricks separating. Glue there and you've built a permanent 2-cell device.

⚠️ **Keep every adhesive away from the cam, the linkage feet and the dot holes.** A drop of
hot glue in the mechanism is far harder to remove than a bad solder joint.

## The 5-second test that beats any coating

**Tug it.** Pull each wire firmly by hand before you insulate anything. A properly soldered
joint will not come off — if it moves, no glue on earth will save it. Redo the joint.

---

# PART 13 — Flagged for the CAD fork (do not fix here)

1. **Hall module does not fit** the base plate — needs the bare TO-92 desoldered, and a pocket
   that can hold it.
2. **DC jack has no thread or nut** — the pod lid cannot clamp it. Needs either a mechanical
   retainer in the box or a different jack.
3. **ULN2003 pocket is 14mm** — drives the solder-flat requirement. It still needs real board/tail measurement and retention proof.

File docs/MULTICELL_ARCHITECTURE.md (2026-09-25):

# Getting from one cell to a readable line

**Written 2026-08-19. Architecture study — nothing here is built yet.**

Braillix today is **one cell, 68 mm wide**. A single character at a time.

That is fine for showing how a braille cell works. It is not enough to read a sentence, and it
cannot show a mathematics symbol at all — Nemeth code writes multiplication and division as **two
cells each**, and fractions use opening and closing indicators spanning several cells. Two cells
68 mm apart are not two cells to a reader. They are two separate objects.

This document asks one question: **can Braillix reach a readable line without becoming expensive?**

---

## 1. The wall

Cell pitch problem

Standard braille cells sit **6.1–6.5 mm apart**. That single number decides everything, because
anything placed at *every* cell has to fit inside it.

| Per-cell actuator | Width | Verdict |
|---|---|---|
| Piezo bimorph reed | ~2 mm | fits — and costs ~$100/cell |
| N20 micro gearmotor | 10–12 mm | **1.9× too wide** |
| 28BYJ-48 stepper | 28 mm | 4.5× too wide |
| Braillix cam disc | 44.4 mm | 7.2× too wide |
| Braillix cell today | 68 mm | 11× too wide |

**Only piezo fits — and piezo is precisely why commercial displays cost $4,000 and up.** The cheap
motto and one-actuator-per-cell are in direct conflict. That is not a Braillix problem; it is the
central problem of the whole field.

### Ideas that hit the wall

**Two motors in one cell, two letters.** The 28BYJ-48's shaft is off-centre, so two cans can
interleave — but the motor was never the constraint. Two **cam discs** need about 44 mm between
centres. Still 7× too wide. Costs weeks, does not produce a readable line.

**Eight motors for eight cells.** 8 × ₹150 of motors is affordable. 8 × 68 mm of box is 544 mm.
Geometry kills it, not cost.

**N20 gearmotors.** Smaller and much faster — but still about 2× too wide, and being DC motors they
have no step counting, so each one needs an encoder or hard stops. More parts, more cost, still no.

---

## 2. Two things that *are* worth taking from the brainstorm

**Splitting the cell across two 8-state discs is a genuinely good idea** — just not for scaling.
Three dots per disc means 8 states, 45° per slice, and the cam ramp problem (R-07) disappears:

| states | radius | ramp | pressure angle |
|---|---|---|---|
| 64 (today) | 12.8 mm | 1.1° | **78.5°** — unclimbable |
| 8 | 12.8 mm | 40.5° | **7.9°** — comfortable |

Two things it does **not** do, both counter-intuitive:

- **It does not make refresh faster.** Rotation time depends on the *angle* travelled, not the
  number of states. 180° is 180° whether that is 32 slices or 4.
- **Shrinking the disc does not help the ramp.** At minimum size the dwell arc equals the foot
  width and the pressure angle collapses to `atan(lift x pi / 2 x foot)` = **51.5°**, regardless of
  radius or state count. The disc must be *large relative to its state count*, not small.

---

## 3. The architecture that escapes the wall

Travelling cam architecture

Stop giving every cell an actuator. Let **one cam head travel along a line of latching pins**.

Each cell then contains nothing but six 1.7 mm pins. Nothing bulky sits at the cell, so standard
6.2 mm pitch becomes achievable — and **the number of motors stops scaling with the number of
cells**. Four cells need two motors. So do eight. So do twenty.

This is the same family of approach that lets line-at-a-time displays reach far lower per-cell
costs than one-actuator-per-dot designs. Worth researching properly and citing at the panel; do not
quote figures you have not checked yourself.

### The refresh cycle

Refresh cycle

**A cam can only push.** It cannot pull a latched pin back down. So every refresh is two phases:

1. **Reset** — a bar sweeps the line and pushes every pin flat.
2. **Set** — the head visits each cell, the cam rotates to that character's state, the lifted
   linkages push the required pins up, and the latch holds them.

Once set, the line holds with **zero power**.

### Speed: be honest about this

| | |
|---|---|
| Per cell | ~1.5–2 s, dominated by cam rotation |
| 4 cells | ~8 s |
| 8 cells | ~15 s |

**A leadscrew will not work.** Even at 8 mm/rev, a 28BYJ-48 needs about 16 s just to traverse four
cells. It has to be a **GT2 belt** — a 20-tooth pulley moves 40 mm/rev, roughly 5× faster.

15 s per line is acceptable for a maths line you set once and then read. It is **not** acceptable
for continuous scrolling. Say so plainly rather than letting a panel discover it.

---

## 4. The one real unknown: the latch

Latch options

Everything else here is ordinary mechanism. The latch is the assumption the architecture rests on.

Each pin must **hold about 0.4 N** so a dot does not collapse, while still yielding to a reading
finger pressing with only 5–15 g. Too weak and the line sags. Too strong and the cam stalls trying
to set it.

| | Cost | Notes |
|---|---|---|
| **Silicone sleeve friction** | ~₹50 | A short length of silicone tube per pin. Fully printable, no magnets. Force tuned by interference fit. **Start here.** |
| **Magnetic detent** | ~₹200 | Small magnet per pin plus a steel plate. More repeatable, but 24 magnets to place and align. |

> ### Test this first, on a 4-pin coupon
> Print four pins, four guides and both latch styles. Load them with a gram scale. Do not design a
> single other part until one of them holds 0.4 N and releases under a fingertip.
> This is a one-evening test that decides whether the next six weeks are worth starting.

---

## 5. What carries over, what is new

**Carries over unchanged** — this is the strongest argument for the approach:

- the 64-state cam encoding and the `DOT_TO_BIT` mapping (`sim/extract_params.py`)
- the cam disc itself (`cad/scad/braille_cam.scad`) — already ordered in resin
- hall-sensor homing, step counting, shortest-path rotation
- the 3D simulator, which can be extended to show the carriage

**New work:**

- GT2 belt, pulleys and a carriage — plus one extra motor
- 24 latching pins at 2.5 mm dot / 6.2 mm cell pitch
- a reset bar and its actuation
- re-converged linkages: the current arms fan out to a 4.8 x 5.2 mm cluster, a standard cell needs
  2.5 x 2.5 mm

---

## 6. Recommendation

**Build the single cell first. Do not abandon it.**

Nothing in this project has ever been physically assembled — no dot has gone up and come back down.
The parts are already paid for and arriving. The single cell is the guaranteed demo, and it settles
**R-07** (whether the cam ramp is climbable at all) before that assumption gets replicated across
24 pins.

Then, and only then:

1. **Latch coupon.** One evening. Decides everything downstream.
2. **Build four cells, not eight.** Half the pins, the same architectural proof — and "it scales by
   lengthening the belt" becomes a demonstrated claim instead of a hope.

### A note for later

If Braillix is ever commercialised rather than submitted, **check patents in this space first**.
There is prior art around micro-motor and cam actuation of braille pins, and at least one
open-source project in India was shut down over it. Irrelevant for academic work. Very relevant the
day it stops being academic.

---

## Sources for the numbers

Every dimension is read from the CAD, not from memory:

| Number | Where from |
|---|---|
| 6.2 mm cell pitch, 2.5 mm dot pitch | braille standard (Library of Congress / Marburg Medium) |
| 44.4 mm cam disc, 68 mm cell | `cad/scad/mech_layout.scad`, `cad/scad/outer_box.scad` |
| pressure angles | computed from `pin_lift`, `track_r`, `angular_ramp_fraction` |
| Nominal 4096 steps/rev, 64 steps/position; owned motor requires Hall-to-Hall calibration | `firmware/breadboard_test/breadboard_test.ino` |
| traverse timings | 28BYJ-48 at 800–1000 steps/s, belt versus leadscrew |

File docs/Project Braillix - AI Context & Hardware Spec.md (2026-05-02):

# **SYSTEM PROMPT & PROJECT CONTEXT FOR CLAUDE**

**Target AI**: Claude (Anthropic)

**User Persona**: Mridul (Hardware Lead) & Atishay (Hardware Engineer)

**Background**: The users are final-year Computer Science (CS) students. **They have ZERO prior hardware engineering experience.** **Budget Constraint**: Strictly under ₹15,000 INR (\~$180 USD). They cannot afford multiple failed prototypes or expensive commercial parts. Solutions must be clever, cheap, and leverage 3D printing or cheap 2D laser cutting.

**Focus**: The user is ONLY interested in the Hardware, Mechanical Design (CAD/OpenSCAD), and Embedded Microcontroller logic (ESP32/Raspberry Pi hardware interfacing). *Do not output software-side AI/OCR logic unless explicitly asked.*

## **1\. PROJECT OVERVIEW: "BRAILLIX"**

Braillix is an affordable, refreshable Braille display designed for the classroom. Existing piezoelectric Braille displays cost thousands of dollars. The previous iteration of this capstone project used Solenoids, but it was a disaster—it drew too much power, melted the plastic, and was too bulky.

**The Pivot**: The team has pivoted to an **Indexed-Cam Architecture**. Instead of 6 expensive motors per Braille cell, they are using **1 cheap stepper motor per cell** that rotates a 3D-printed cam disc to 64 discrete angles, pushing pins up and down mechanically.

**The Vision**: A connected classroom. The teacher uploads a PDF to a main server. The text is translated to Braille/Nemeth code. The students have modular, snap-together Braille cells on their desks. Each student has a "Forward", "Backward", and "Submit" button to read the text letter-by-letter at their own pace.

## **2\. THE MODULAR "LEGO" ARCHITECTURE (ELECTRONICS)**

The system is built on a "Master-Slave" daisy-chained network using identical, modular cells that a visually impaired user can easily snap together using magnets.

* **The Brains**: Every single Braille cell has its own cheap **ESP32** microcontroller.  
* **The Physical Connection**: The cells snap together using magnetic **4-pin spring-loaded Pogo Pins**. The 4 pins are: 5V (Power), GND (Ground), TX (UART Transmit), RX (UART Receive).  
* **The Communication**: UART Daisy-Chaining. Cell 1's TX physically touches Cell 2's RX. When the teacher's server sends the word "MATH", Cell 1 keeps "M", and sends "ATH" to Cell 2\. Cell 2 keeps "A", and sends "TH" to Cell 3\.  
* **The "Who Am I" Auto-Detect (The Voltage State Trick)**:  
  * To prevent the software team from writing complex addressing algorithms, the ESP32s figure out their order based on raw physics.  
  * On boot-up, every ESP32 turns on an **Internal Pull-Down Resistor** on its RX pin, while turning its TX pin HIGH (3.3V).  
  * If a cell is snapped to another cell on its left, the left cell's HIGH TX pushes voltage into the current cell's RX. It reads HIGH, knows it's a **Slave**, and waits for serial data.  
  * If a cell has *nothing* snapped to its left, no voltage comes in. The pull-down resistor forces it LOW. It instantly knows it is the **Master (Cell 1\)**, turns on its Wi-Fi, and connects to the teacher's server.

## **3\. THE MECHANICAL "SANDWICH" (THE ACTUATOR)**

The single cell is constructed in a stacked vertical arrangement.

### **A. The Motor & Base Plate**

* **Motor**: **28BYJ-48 Stepper Motor** (cheap, high torque gearbox, D-shaft). Driven by a ULN2003 board.  
* **Base Plate**: 3D printed. Has a 1.5mm recess on the bottom to seat the round motor body (preventing shear stress on screws). Has a 3mm pocket on top for the Cam Disc. Has 4 corner standoffs (3.5mm high) to support the Top Plate.

### **B. The Cam Disc (The Motion)**

* **Design**: A 33mm 3D-printed disc (SLA Resin preferred for smoothness).  
* **Tracks**: It features **6 concentric circular tracks** on its top face, mapping to the 6 Braille dots.  
* **States**: It has 64 discrete angular steps. At any given angle, the tracks either have a "bump" (0.8mm high) or remain flat.  
* **Crucial Fixes Made**: It has a 2mm solid "floor" underneath so the tracks don't print as 6 loose rings. The track gap is 0.1mm to 0.4mm depending on the printer. The center hole is a "D-Cut" to lock onto the 28BYJ-48 motor shaft without slipping.

### **C. The Linkages (The Pins)**

* **The Problem**: Hand-bending 6 tiny wires to reach from the wide circular cam tracks (8mm to 18mm radius) into the tiny rectangular Braille grid (2.5mm spacing) is impossible for beginners.  
* **The Solution**: **2D Laser-Cut Metal Linkages**. 6 flat metal shapes (1mm thick) cut from stainless steel or aluminum. They are shaped like "cranks" or "stair-steps". The bottom tip is rounded (sanded) to glide on the cam track. The horizontal arm bridges the distance. The top nub acts as the Braille dot.  
* **Tactile Fix**: Since 1mm flat metal feels sharp to a blind reader, a tiny drop of UV resin or superglue is applied to the top tip to form a 1.4mm smooth dome.

### **D. The Top Plate**

* **Design**: Screws into the Base Plate standoffs. It features a scooped "Finger Pad" for ergonomics.  
* **Slots**: Because the linkages are flat 1mm metal (not round wire), the Top Plate features **1.2mm rectangular slots** instead of round holes. This prevents the metal from twisting or jamming.  
* **Return Mechanism**: Tiny compression springs sit in pockets under the Top Plate, pushing the metal linkages constantly down against the Cam tracks.

## **4\. CRITICAL HARDWARE CONSTRAINTS & FIXES**

* **The Power Trap**: 5 stepper motors moving at once will pull \~1.2 Amps, causing a voltage drop that will reset the ESP32s (brownout).  
  * *Fix*: The 5V line running through the Pogo pins connects *directly* to the Motor Drivers. The ESP32s tap into this line separately. The ESP32 GND and Motor GND **must** share a Common Ground.  
  * *Software requirement*: Motor movements must be staggered by \~50ms.  
* **Motor Amnesia**: Stepper motors forget their position on reboot.  
  * *Fix*: A small Hall-Effect sensor on the Base Plate and a tiny magnet on the Cam Disc. The device "homes" itself on boot-up by rotating until the sensor triggers.  
* **The Logical Clutch**: There is no physical mechanical clutch (too expensive/complex).  
  * *Fix*: UX protocol. The device emits a beep, the user lifts their finger, the motor spins to the next letter, stops, and beeps again indicating it is safe to touch.  
* **Friction**: The 1mm laser-cut metal feet *must* be sanded smooth and lubricated with Silicone Lube or White Lithium Grease to prevent them from shredding the 3D-printed resin cam.

## **5\. CLAUDE'S DIRECTIVE**

As Claude, your job is to assist Mridul with any upcoming hardware challenges.

1. **Never suggest expensive overhauls.** If a mechanical issue arises, fix it with a cheap 3D-printed jig, an OpenSCAD code tweak, or a basic electronic component (resistor, diode, switch).  
2. **Write robust OpenSCAD.** If Mridul needs to adjust the Cam, Base Plate, or Top Plate, provide optimized, parameter-driven OpenSCAD code.  
3. **Provide exact wiring.** If asked about wiring the ESP32, ULN2003, Pogo Pins, or buttons, provide exact GPIO pin mappings and explain *why* (e.g., avoiding strapping pins on the ESP32).  
4. **Speak as an Engineering Mentor.** Guide them away from common beginner hardware traps (like forgetting common grounds, ignoring material tolerances, or ignoring thermal limits).

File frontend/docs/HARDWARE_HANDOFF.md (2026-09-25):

# Braillix — software → hardware handoff

What the hardware team needs from the software side, and the three things we need back.

This is the mirror of your `SOFTWARE_TEAM_README`. Everything below is implemented and tested; the
protocol is not a proposal.

**Credit where the physics lives:** the hardware architecture this seam is built against — the
brain-pod/muscle-cell split, the I2C chain, the 64-position cam, the homing behaviour — is the
hardware team's design (Atishay, lead · Mridul), stated in their `SOFTWARE_TEAM_README` and
implemented faithfully here. The software half drives their machine; it did not invent it.

---

## 1 · What the software already does

The laptop turns a maths expression into a **cam position per cell, 0–63**, and sends it. It never
sends braille, letters, or a language — only numbers. That is deliberate, and it is what your §2
asked for: the braille logic can change completely without anyone reflashing a board.

Three transports, one protocol (`PROTOCOL.md`):

| | When to use it |
|---|---|
| **Simulator** | Nothing plugged in. This is the primary mode and it is complete. |
| **USB (Web Serial)** | **Recommended for the demo.** No network, no IP address, no router. |
| **Wi-Fi** | Exactly the endpoints in your §7. Needs the laptop and pod on one network. |

There is also `tools/virtual-pod` — a pod that isn't there, speaking the real protocol. You can test
firmware behaviour against it, and we test the app against it, before any hardware exists.

## 2 · Firmware we have written for you

Both are in `firmware/` and are written against the same spec the laptop uses.

**`firmware/pod/pod.ino`** — ESP32 brain pod.
- Serves the protocol over **both** USB serial (115200, newline-delimited JSON) and Wi-Fi HTTP, from
  one command handler. Leave `WIFI_SSID` blank and it is a USB-only device, which is a perfectly
  good configuration.
- Scans I2C `0x20`–`0x27` on boot and on `/chain`, and reports what actually answered. Nothing
  assumes a cell count anywhere.
- Skips any cell already at the requested position — the cheapest motor command is the one never
  sent.
- Debounced Prev/Select/Next with long-press on Select.
- No external libraries beyond the ESP32 core, so it flashes without a library-manager setup.

**`firmware/cell/cell.ino`** — muscle cell.
- I2C address read from the solder jumpers at boot, so **one binary flashes every cell**.
- Hall-sensor homing, bounded to one revolution: if the magnet never appears it reports a fault
  rather than spinning forever.
- 4096 half-steps per revolution, 64 per cam position, exactly as your §5 states.
- **Takes the shorter way round the cam.** 60 → 2 is six positions forward, not fifty-eight
  backward. The cell is the only part of the system that knows where it currently is, so this is
  the only place the decision can honestly be made.
- Cuts coil current when idle, because a 28BYJ-48 held in position gets hot and a display spends
  most of its life not moving.

## 3 · The three things we need from you

### 3.1 Confirm the cam bit order — 30 seconds, no code

Your §3 flags this as unconfirmed, and it is the single most likely cause of "the dots are wrong".

1. Open Braillix → **Hardware**.
2. Press **dot 1**. Every cell should raise the **top-left** dot only.
3. If a different dot rises, change the "cam track bit" for dot 1 in the table until it is right.
4. Repeat for dots 2–6, then press **Copy config for the hardware team** and send us the JSON.

No firmware change, no rebuild, no code. If the physical cam is wired differently from the default,
that is a setting.

**Sanity check without hardware:** with the default mapping, dots 1-2-5 is cam position **19** —
the worked example in your own §3. The Hardware screen shows this live.

### 3.2 Confirm the cell order along the dock

If cell 1 turns out to be on the right, tick "Cell 1 is on the right" on the same screen. Also a
setting.

### 3.3 Tell us the I2C addresses you actually fitted

The pod discovers them, so we do not need to be told in advance — but if a jumper is wrong, the pod
will report (say) three cells when four are fitted, and Braillix will believe it. The Hardware
screen shows the discovered addresses; check them against the boards once.

## 4 · What happens when things go wrong

Every failure is reported on screen with what to do about it, rather than as a silent nothing:

| Symptom | What Braillix says |
|---|---|
| Pod not on the network | `could not reach 192.168.x.x` + check the network or use USB |
| No cells answered the I2C scan | `the pod found no muscle cells` + check 5V/GND/SDA/SCL and the jumpers |
| Pod says 4 cells but lists 3 addresses | refuses to connect and says so — it will not guess |
| A cell does not acknowledge | the frame is rejected rather than half-applied |
| Wrong number of positions sent | `expected 4 positions, got 3` — never silently truncated |

## 5 · Things we would like, but do not need

Not blockers. Listed so they are on the record rather than discovered late.

- **A second cell.** Everything is written for *N* cells and tested from 1 to 40, but two real cells
  would let us verify ordering along a physical dock rather than in a simulator.
- **The `braille_cam.scad` cam file.** We would like to generate the Cell Atlas sheet directly from
  the cam geometry rather than from the default mapping.
- **A cell status read.** The protocol has it (`0xFF 0x02`, then read one byte); the firmware
  implements it; nothing on the laptop side depends on it yet. If a cell can report "fault", we can
  show which cell is stuck instead of just "something did not acknowledge".

## 6 · Try it right now, with no hardware

```bash
npm install
npm run dev          # the whole product, simulated
npm run pod          # in another terminal: a pod that isn't there
```

Then in Braillix: **Hardware → Wi-Fi pods → `127.0.0.1:8080` → Connect**. The terminal running the
virtual pod draws the dots as they change and reports how much motor time each frame would cost.

Print the **Cell atlas** screen and hold it against the physical cam — all 64 positions, their dots,
and what each one means in Nemeth, on one sheet.

---

## Added 20 August 2026 — several pods, and what they mean together

Braillix now asks a question it used to answer by assumption. With more than one pod address, the
Device screen offers two arrangements, and the software never guesses between them:

**Joined** (`/layout`, as in §4B of your handoff). The pods are one long display. Pod 0 shows the
first cells, pod 1 the next, and the laptop sends each pod its own slice along with the overall
layout so two pods can never disagree about the message. Total width = the sum of the pods.

**Mirrored** (`/show` to every pod). Every pod shows the *same* cells — one teacher, one
expression, a display in front of each child. Two things about this are worth knowing on the
hardware side:

1. **The width is the smallest pod, not the largest.** A frame the small display cannot show would
   leave one child reading a truncated equation with no way to know that is what happened.
2. **A wider pod has its spare cells blanked**, in the same frame. Nothing is left showing what it
   was showing before.

Nothing on the pod changes for either mode. Mirrored, a pod receives an ordinary `/show` with a
full-width `positions` array, exactly as a single pod does today. The whole difference is in the
laptop.

Both are exercised by the conformance suite against two virtual pods (`npm run pod`), and the
mirrored test asks the pods what they are showing rather than trusting what the laptop believes it
sent.

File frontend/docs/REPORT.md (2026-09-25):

# Braillix — Project Report Source Document

Prepared 22 August 2026 from the codebase as deployed at https://braillix.vercel.app
(repository: github.com/SHV27/braillix, branch `main`). All numbers in this document were
measured on that build, on real hardware or in a real browser, on the dates given. Written
for the report author; no marketing language.

Team: Shaurya Verma (Software), Harshita (Software), Aniket (Software), Atishay (Hardware),
Mridul (Hardware).

## 1. Problem statement

Blind students in India largely stop studying mathematics between classes 7 and 8. The
proximate causes are documented: mathematics teaching in schools for the blind relies on the
Taylor frame and the abacus; braille textbooks are shared rather than individual; digital
mathematics content is the least screen-reader-accessible subject area; and refreshable
braille displays that could help are either imported and expensive (₹1.5 lakh and above for a
40-cell line) or not designed for mathematics teaching at all. No commercially available
device addresses the classroom act itself: a teacher working through a problem on a
blackboard, line by line, while the class follows.

Braillix addresses that act. The teacher writes, types, or photographs whatever she is
teaching at that moment — full worded questions, equations, worked steps — and each line is
rendered as mathematical braille on a refreshable display the student reads by touch. The
software is designed for a teacher whose technology experience is WhatsApp, YouTube and
Facebook, and it requires no account, no server, no API key and no network after first load.

The project is split in two: a hardware team building the display (an ESP32 "brain pod"
driving motorised "muscle cells", one braille character per cell), and this repository — the
complete software half, which is fully functional with no hardware attached.

## 2. What the product does

The interface is a single surface designed to read as a blackboard: the lesson stands on it
as typeset print, the braille cells sit beneath it, and one input tray (with every school
mathematics symbol permanently visible) is the only place anything is written. Device
configuration and help are behind two doors in the top rail. This is a deliberate v4
redesign: usability testing with the project owner showed that capability which must be
found behaves identically to capability which is absent.

- **The board.** The teacher types a line in ordinary notation (`2x + 3 = 11`, `sqrt(144)`,
  `1/2`, or Hindi text such as `दो संख्याओं का योग 12 है`) and presses Enter. The line joins
  the lesson — a stack of lines, like a blackboard — is translated to braille, sent to the
  display, and spoken aloud. Any earlier line returns to the display with one press. Lessons
  persist across restarts on the same laptop.
- **Handwriting, in place.** Pressing the pencil turns the board's next empty line into a
  writing surface. The teacher writes a step with a finger, stylus or mouse; when the hand
  pauses (1.2 s), the strokes are rasterised to a clean black-on-white image and read by the
  same on-device recogniser the camera path uses (the model was trained on handwritten as
  well as printed formulas — UniMER-1M, handwritten-subset BLEU 0.86). The reading lands in
  the input box behind the print preview and the braille verdict; the teacher's ordinary
  "put on the board" press is the confirmation. If she edits the box by hand, the strip
  never overwrites her text. The committed line keeps her strokes as a faint ghost behind
  the typeset print.
- **Scanning.** Photograph paths, all processed on the laptop with no network: an equation
  photo, and a full textbook question scanned part by part — the teacher drags a box around
  the sentence, then around the mathematics, tags each, watches each be read, corrects
  anything doubtful, and only then sends the assembled line to the board. Keyboard-only
  paths exist for all of it.
- **The confirm gate.** No recognised content can reach the display without explicit teacher
  approval. This is enforced in the type system (a "recognised" lesson line cannot be
  constructed without a literal `confirmed: true`), not by interface convention.
- **Reading.** The pod's own Prev/Select/Next buttons, the on-screen arrows, and
  PageUp/PageDown all drive one pager that walks the lesson continuously: through the panes
  of a long line, then onward to the next line; paging backwards enters a line at its last
  pane. On a one-cell display this makes a whole worked example readable in order. A
  structure-exploration mode folds long expressions into navigable sub-expressions.
- **Verification shown to the teacher.** Every line's braille is read back by independent
  engines that never saw the input (one per braille code on the line) and the agreement or
  disagreement is displayed. Where translation cannot be vouched for, the interface says so;
  it never silently substitutes.
- **Languages.** The full interface, speech, and braille pipeline work in English and Hindi.

Deliberately excluded (by the founder's direction): worksheets, lesson libraries, practice
drills, student records, and any language beyond English and Hindi.

## 3. Technology stack and why each piece

| Layer | Choice | Reason |
|---|---|---|
| Application | Vite 8, React 19, TypeScript 5.9, Zustand 5 | Standard, minimal, static-deployable; one store as the single authority for display state |
| Maths input | Custom natural-notation parser + LaTeX passthrough (`core/mathinput.ts`) | Teachers write `1/2`, not `\frac{1}{2}`; both are accepted by one entry point |
| LaTeX → MathML | temml 0.13 | Small, fast, no server |
| MathML → Nemeth braille + speech | speech-rule-engine 4.1 (Apache-2.0) | The only maintained library that produces both Nemeth braille and MathSpeak-style speech from the same MathML, entirely in the browser |
| Hindi literary braille | Hand-built Bharati Braille tables (`core/bharati.ts`), verified against the NIEPVD/GoI Bharati Braille standard | liblouis's Nemeth table is explicitly unmaintained upstream; Bharati forward+reverse tables were small enough to build and test directly |
| Reverse verification | Hand-built readback engines (`core/readback.ts`, `core/bharatiback.ts`, `core/literalback.ts`) | Independent reconstruction of meaning from dots is the only proof that does not share code (and therefore bugs) with the forward translation |
| Formula recognition | Vision encoder–decoder ONNX model ("formulanet", ~76 MB fp32), run by @huggingface/transformers 4.2 on ONNX Runtime WASM, in a Web Worker | Free, runs offline on modest laptops, reads printed and handwritten mathematics; nothing a student writes leaves the machine |
| Word recognition | tesseract.js 7 (Apache-2.0) with tessdata_fast English + Hindi, fully self-hosted | The words of a textbook question, both scripts, offline |
| Speech output | Web Speech API, voices from the operating system | Free and offline; absence of a voice is reported, never silent |
| Hardware link | Custom `Transport` interface with three implementations: simulator, Web Serial (USB), HTTP (Wi-Fi pods) | One interface means the app cannot behave differently on hardware than in the simulator |
| Testing | Vitest 4 (727 unit tests), Playwright 1.62 (101 end-to-end journeys with screenshots at 390/834/1440 px) | See §7 |
| Deployment | Vercel, static, free tier | No server component exists |

Everything is served from the application's own origin — fonts, braille tables, both
recognition engines and their models. After the first visit a service worker keeps the
application fully functional offline; large model files are cached on first use.

## 4. System architecture and data flow

```
teacher input (type | handwriting on the board | photo | textbook scan)
    → [scan paths only] recognition workers (formula ONNX · tesseract eng+hin)
    → [scan paths only] CONFIRM GATE — teacher sees print + hears speech, approves
    → lesson store (lines of segments: English text | Hindi text | mathematics)
    → translation core: natural notation → LaTeX → MathML → Nemeth cells
                        Hindi words → Bharati cells · English words → Grade-1 cells
    → independent readback (per braille code) → agreement shown to the teacher
    → pager (lesson lines → display-sized panes → cells, sized by the discovered profile)
    → transport (simulator | USB | Wi-Fi pods) → cam positions 0–63 → motors
    ↘ speech (line spoken as it lands)   ↘ on-screen dot rendering (always)
```

Principles enforced structurally rather than by convention:

- **One authority per fact.** The Zustand store owns the display state; a single selector
  derives every frame. The cell count exists nowhere in code — it is discovered from the
  transport (an I2C scan reported by the pod, or the simulator's setting).
- **Observable degradation.** Every optional capability (recognition, speech, USB, pod,
  offline copy) publishes state · reason · fix, rendered as badges and checked by a
  one-button self-test on the Help screen.
- **The previous frame is sacred.** Errors freeze the display at the last good frame and say
  what went wrong; the display never blanks.
- **The build refuses to ship blind.** `app/scripts/assert-assets.mjs` fails the production
  build if any of 11 on-device assets (model weights, ONNX runtime, OCR languages, braille
  tables) is missing from the artifact, and `tools/check-deployed.mjs` asserts they are
  actually served by the live site (21 live checks).

## 5. The hardware interface

Ground truth is the hardware team's handoff document; the software implements its protocol
exactly and ships a zero-dependency emulator (`tools/virtual-pod`, plain Node) that speaks
the same wire protocol, so integration is tested continuously without hardware.

- Pipeline: braille cell (dots 1–6) → 6-bit cam number 0–63 (dot 1 = bit 0) → HTTP to the
  pod → I2C to the muscle cell → stepper motor to one of 64 cam positions (4096 half-steps
  per revolution, 64 per position, hall-sensor homing).
- Protocol: `GET /chain` (I2C scan → cell count and addresses 0x20–0x27), `POST /show`
  (cam positions, full or delta), `POST /layout` (multi-pod slicing so several pods carry
  one message), `GET /buttons` (Prev/Select/Next), `POST /home`.
- The cell count is discovered at connection, never assumed; multiple pods negotiate a
  common layout; a mirror mode shows the same content on every pod for a classroom.
- Physical uncertainties the handoff flags (cam bit order, cell direction, home position)
  are runtime configuration with a ten-second calibration screen (raise one dot on every
  cell), not constants — a wiring difference is fixed by a setting, not a reflash.
- Motion is planned for the shortest cam arc; the status strip reports half-steps moved and
  saved (typically 50–90 % less motor travel than naive rotation).

Verified end-to-end on 21 August 2026 against the emulator: chain discovery reported 1 cell;
the line `2x = 8` put cam 60 (⠼, the Nemeth numeric indicator) on the wire; pressing the
pod's own Next button advanced the application to cell 2 and the pod to cam 6 (digit 2).

## 6. Models used

| Model | Size | Task | Where it runs |
|---|---|---|---|
| "formulanet" vision encoder–decoder (ONNX, fp32) | 76 MB | printed and handwritten mathematics → LaTeX | Web Worker, ONNX Runtime WASM, on the user's machine |
| tessdata_fast `eng` | 2.0 MB (gzipped) | printed English words → text | tesseract.js WASM worker |
| tessdata_fast `hin` | 0.9 MB (gzipped) | printed Hindi (Devanagari) words → text | tesseract.js WASM worker |
| speech-rule-engine mathmaps (en, hi) | ~1 MB | MathML → Nemeth braille and spoken mathematics | main thread, pure JS |

Recognition design: the model's reading is never trusted. It is shown rendered in print,
with a quality judgement and its reasons; below-confidence readings are flagged "not sure —
check this"; when the model is uncertain the same image is read a second time through
different preprocessing and the two readings are compared (agreement is evidence,
disagreement is surfaced as a choice). The teacher can correct any reading in an ordinary
text field before approving it — the same motion as correcting one word of voice typing.

Both recognisers are warmed in the background at application start, with an honest progress
badge, so the teacher's first scan does not pay the load cost.

## 7. Testing and verification results (all measured 21 August 2026)

| Evidence | Result |
|---|---|
| Unit tests (Vitest) | 727 / 727 passing |
| TypeScript, ESLint | clean |
| End-to-end journeys (Playwright, real browser, production build) | 101 / 101 passing, with screenshots at 390 / 834 / 1440 px and a no-horizontal-scroll assertion per screen. Includes two handwriting journeys that draw real mouse strokes on the ink strip, wait for the on-device reading, and follow it through the confirm gate onto the board — and one that proves a hand correction is never overwritten by a later reading |
| Curriculum coverage | **232 / 232 lines across 27 topics** (NCERT arc, classes 1–12), with the senior classes at full depth after a v5 gap audit: sets/relations/functions, inverse trigonometry, permutations–combinations and the binomial theorem written as `nCr`, sequences, complex numbers, conics, calculus from limits to differential equations (including `int u dv = uv - int v du`), vectors and 3-D, matrices and determinants, conditional probability and Bayes' theorem, and a linear-programming objective. Every line is independently read back from its cells. Regenerable as `docs/ACCURACY.md`; re-runnable live from Help ("Prove the syllabus") |
| Senior-syllabus gap audit (22 Aug 2026) | 48 deep class-11/12 concept lines stress-tested: 12 initial failures in 7 classes (set words split as English, `nCr` read as a word, the conditional bar, spaced dot products, `arcsin`, the prime cell, `f: A -> B`) — all closed with parser/checker rules and folded into the tested syllabus |
| Multi-pod classroom | Two protocol-accurate virtual pods of different widths (4 and 2 cells) connected mirrored: both wires received the same frame, the wider pod's spare cells blanked, verified live with wire logs and screenshot (`docs/shots/mirror-two-pods.jpeg`). A chain-shaped validation bug rejecting unequal mirrored pods was found by this live test and fixed with regression tests |
| Golden vectors | Nemeth output asserted against dot patterns from the official BANA Nemeth 2022 code book; Bharati output against the NIEPVD/Government of India Bharati Braille standard |
| Round-trip law | Every expression's cells are read back by engines that share no code with the forward translation; disagreement is displayed, and the cosmetic LaTeX tidier is tested to never change the resulting braille |
| Recognition speed | Cold press-to-result was 64.2 s (model load dominated); after background warm-up, 1.25 s press-to-result measured even when scanning immediately after page load; steady-state 0.7–2.5 s per scan on a mid-range laptop |
| Recognition accuracy (spot, real browser) | Handwritten sample → `x^{2}+5x=6` correct; unseen stacked-fraction image → `\frac{x^{2}+1}{2}=5` correct; unseen printed sentence + equation → words 93–94 % confidence and exact, equation exact; unseen Hindi sentence → exact at 88 % confidence |
| Hardware protocol | Emulator loop verified live (see §5); a shared conformance test suite runs against all three transport implementations |
| Deployed site | `tools/check-deployed.mjs`: 21 / 21 checks — page, service worker, Nemeth tables, manifest, icons, model weights, ONNX runtime, OCR worker and both language files all served |
| Accessibility | Landmarks/headings/labels/focus asserted by automated tests on every screen; ARIA live regions on every state change; full keyboard operation including a no-drag scanning path; `prefers-reduced-motion` honoured. Not a substitute for user testing with screen-reader users, which has not been done |

## 8. Limitations (honest)

- **Recognition is not perfect and is designed around that fact.** Handwriting quality,
  page skew and low light reduce accuracy; the mitigation is the visible quality judgement,
  the second reading, and the mandatory human confirmation — not a claim of perfection.
- **Handwritten words (as opposed to mathematics) are weak.** The ink strip's "Words" mode
  routes handwriting through Tesseract, which is trained on print — careful, print-style
  writing works; cursive and handwritten Devanagari genuinely do not, and no free
  browser-runnable handwritten-Devanagari model existed as of August 2026 (researched, with
  sources, in the project decision log). Mathematics ink is the strong path; the confirm
  gate carries the rest.
- **The braille pipeline is Grade 1 plus Nemeth.** Grade 2 (contracted) literary braille is
  not implemented. The Indian mathematics braille code is treated as Nemeth-compatible; a
  symbol-level diff against the NIEPVD manual (print-only) has not been performed.
- **Nemeth is rendered linearly.** Spatial layouts (long division worked in columns,
  matrices as grids) are linearised or explored as structure, which is a genuine pedagogical
  compromise on a one-line display.
- **Single-line hardware.** Multi-line spatial reading is out of scope for both teams.
- **One real muscle cell existed at integration time.** Multi-pod behaviour is verified
  against the emulator, not against physical multi-pod hardware.
- **Screen-reader user testing has not been conducted**; accessibility is asserted
  structurally and by automated test only.
- **Speech depends on operating-system voices**; a machine without a Hindi voice speaks
  English and says so on the badge.

## 9. Future work

- Evaluate Texo (2026, AGPL, ~20 MB) as a smaller, faster formula-recognition model.
- Grade 2 contractions; symbol-level reconciliation with the NIEPVD Indian mathematics code.
- Multi-threaded ONNX inference (attempted; session initialisation hangs inside a nested
  worker under cross-origin isolation — needs investigation outside that configuration).
- Per-pod cursors so several students can read different lines of the same lesson
  simultaneously, with a "bring everyone to me" teaching action.
- Automatic page-layout detection so a full textbook page needs no manual region boxes.
- Field testing in a school for the blind, including screen-reader users and teachers.

## 10. Repository map

```
app/            the product (Vite + React + TS)
  src/core/     translation engine: input → LaTeX → MathML → Nemeth/Bharati → cells → cams
  src/recognise/ on-device recognition (formula worker, tesseract words, preprocessing)
  src/transport/ simulator | Web Serial | HTTP pods, one interface + conformance suite
  src/ui/       the blackboard surface, chalk tray, ink strip, cells strip, drawer, i18n
  src/lesson.ts the blackboard's memory: lesson lines, selection, the typed confirm gate
  src/draft.ts  the chalk in the hand: one owner of the line being written
  src/ink.ts    ghost ink: the teacher's strokes kept behind recognised lines
firmware/       ESP32 pod + muscle-cell sketches (hardware team's domain)
tools/          virtual pod emulator · model fetchers · accuracy report · deployed-site check
docs/           PROTOCOL.md (wire protocol) · ACCURACY.md (generated) · this report
```

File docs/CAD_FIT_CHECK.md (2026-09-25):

# CAD FIT CHECK — will the real parts fit the printed parts?

> ## ⚠️ SUPERSEDED IN PART — read `CAD_CHANGELOG_v7.5.md` alongside this
>
> This document audited **v7.2/v7.3**. On 2026-07-30 a repair pass (**v7.5**) fixed every
> defect that did not require calipers. The findings below are preserved as the *record of
> what was wrong*, but the following are **FIXED and no longer describe the source**:
>
> | Section | Defect | Status |
> |---|---|---|
> | §2a | Hall pocket entirely inside the cam pocket | ✅ rebuilt on the plate underside at (0, 17.35) |
> | §2c | Homing magnet craters the cam tracks | ✅ blind 1.2mm pocket, 3×1mm magnet (it craters **three** tracks, not two — §2c undercounts) |
> | §3a | Right motor screw opens into the spring cavity | ✅ spring cavity deleted; pilots instead of clearance holes |
> | §3b | Left ear hole 0.35mm from the plate edge | ✅ `base_length` 56 → 58, wall now 1.35mm |
> | §5 | Muscle-board bosses clash with the ULN2003 | ✅ bosses now default OFF |
> | §6a | ESP32 overruns the pod by 1.75mm | ✅ `pod_length` 64 → 68 |
> | §6c | USB cutout ~2mm too high | ✅ arithmetic bug fixed (ignored `hdr_channel_depth`) |
> | §6d | USB cutout too small for a real plug | ✅ 10×7 → 13×9 |
> | §7 | Guessed panel-jack hole/cradle | ✅ removed; current lid uses an outside inline pigtail, cable-only slot, and internal tie post |
>
> **Still open after the completed measurements** (see `MEASUREMENTS_NEEDED.md`):
> §4c motor/cam vertical-stack re-derivation · §2b physical Hall-pocket dry-fit ·
> §7 selecting the smallest safe inline-pigtail cable slot with the printed coupon.

> ## 2026-07-31 measurement-research update
>
> The online and owned-part pass is recorded in `MEASUREMENT_RESEARCH.md`.
>
> - Motor M1–M9 now include the fit-critical owned readings; M5 is 3.0mm across flats.
> - M11b is measured at 1.6mm. The recess is also 1.6mm, so geometry passes but a printed
>   dry-fit is still required because there is no manufacturing margin.
> - M18 is a 30-pin USB-C ESP32 and M21 is measured at 25.6mm. The live socket channels now use it.
> - The owned power part is an inline female DC pigtail. For the current pod its body stays outside;
>   only the cable pair crosses the lid and an internal tie post carries pull load. Select the
>   smallest 5x3 / 6x4 / 7x5 slot with `pigtail_slot_coupon.gcode`.
>
**Date:** 2026-07-29
**Scope:** physical fit of purchased/owned components inside the v7.2 printed parts.
**Status of the build:** nothing has ever been assembled. This is the last check before spending.

## How to read this document

Every statement is tagged:

- **[SCAD]** — read directly out of the OpenSCAD source in `cad/scad/`. This is fact about the
  *printed part*.
- **[SPEC]** — a published nominal figure for a standard catalogue part (28BYJ-48, 6x6 tactile
  switch, 5.5/2.1 barrel jack, micro-USB). Standard parts still vary between clone vendors.
- **[ASSUMED]** — a number somebody typed into the CAD about a physical object that has never
  been measured. Treat as fiction until a caliper says otherwise.

**Historical note:** when this v7.2/v7.3 audit was written, the "Real part needs" column was unmeasured.
Several owned-part dimensions have since been measured; use `MEASUREMENT_RESEARCH.md` as the current evidence table.

---

## 1. SUMMARY TABLE

| Component | CAD provides [SCAD] | Real part needs | Verdict | Action |
|---|---|---|---|---|
| **Hall sensor (MH-Sensor-Series / KY-024 module)** | 5.3 x 4.3 x 3.0 mm pocket at (0, +20) in `base_plate` | PCB module ~15 x 11 x 1.6 mm + ~11 mm of 4-pin header [ASSUMED] | **FAILS** | Desolder the bare sensor, or move the module out of the plate entirely |
| **Hall pocket itself** | pocket floor z=2; Ø46 cam pocket floor also z=2, and the pocket lies **entirely inside** r=23 | any pocket at all | **FAILS** | The pocket is 100% subsumed by the cam pocket — it does not exist as a feature |
| **Cam homing magnet Ø3x2** | Ø3.2 x 2.0 pocket at r=17.35 in a **2.0 mm** disc floor | 3x2 mm disc magnet — **not owned** | **FAILS** | Pocket is a through-hole that punches a Ø3.2 crater through cam **tracks 2 and 3** |
| **28BYJ-48 motor body** | Ø29 seat, 35 mm hole spacing, Ø4.3 holes, body centre at x=-8, 19 mm of z-space | body Ø28, 35 mm spacing, Ø4.2, ~8 mm offset, 19 mm can [SPEC] | **UNVERIFIED** | Never measured. 8 caliper readings required (§4) |
| **Motor right mounting screw** | hole at (+9.5, 0) falls **inside** the 22 x 16 spring-cavity through-window | material to clamp against | **FAILS** | Motor can only be held by ONE screw |
| **Motor screw head vs cam** | left hole at x=-25.5 is clear; right hole at x=+9.5 is under the Ø46 cam disc | screw head clearance | **FAILS** | No counterbore modelled; head fouls the cam floor |
| **Cam on shaft (double-D bore)** | Ø5.2 clipped to 3.2 flats; **through-hole**, real engagement = hub 4 + floor 2 = **6 mm** | 5.0 mm shaft, 3.0 mm across flats, ~10 mm long [SPEC] | **UNVERIFIED / marginal** | Clearances fine on paper; z-stack is wrong (§5) |
| **Cam z-stack vs motor face** | hub bottom z=39, motor top face z=41 | hub cannot go below the motor face | **FAILS** | Cam bottoms on the motor and sits ~2 mm high → all six dots permanently proud |
| **Shaft protrusion** | cam surface z=45; a 10 mm shaft reaches z=51 | shaft must not enter the dot cluster | **FAILS (conditional)** | Shaft passes through the open bore into the linkage risers at x=±2.4 |
| **ULN2003 module, wires soldered flat** | 36 x 46 x 16 pocket + 2 mm mid-plate relief slot = 18 mm | ~35 x 32 x ~12 mm [ASSUMED, established earlier] | **FITS** | Solder wires flat. Watch the 0.5 mm/side X clearance |
| **ULN2003 module, vertical Dupont jumpers** | same 18 mm max | ~20 mm as-wired [ASSUMED] | **FAILS** | Confirmed: 20 > 18. No vertical jumpers |
| **ULN2003 vs muscle-board bosses** | 4 mm tall bosses at (±14, ±19) rise from the pocket floor | flat floor | **UNVERIFIED** | If the board is ~35 mm in Y it clips the y=±19 bosses |
| **ESP32 DevKit length in pod** | cavity ±28 in X; board 51.5 centred at x=+4 → spans -21.75 .. **+29.75** | board must end inside x=+28 | **FAILS** | 1.75 mm interference with the +X (dock) wall |
| **ESP32 DevKit width / row pitch** | `devkit_width` 28.0, `hdr_row_pitch` 25.4 [ASSUMED] | 30-pin DOIT V1 is commonly ~25.4 wide / 0.9" pitch; 38-pin is ~28 / 1.0" [SPEC-ish] | **UNVERIFIED** | The CAD numbers describe the **38-pin** board; the docs say 30-pin |
| **USB cutout alignment** | cutout z 12.5 .. 19.5; board top sits at z=10.5 (8.5 strip − 1.0 channel recess) | port body ~10.5 .. 13.0 | **FAILS** | Hole sits ~2 mm too high; only ~0.5 mm overlaps the port |
| **USB cutout size** | 10 x 7 mm | micro-USB overmould commonly ~12 x 8 [SPEC-ish] | **UNVERIFIED** | Plug may not enter |
| **Headroom under pod lid** | board top z≈10.5, cavity top z=54 | a few mm | **FITS** | 43 mm spare — grossly over-tall, but no clash |
| **Power cable slot (current source)** | rounded 6 x 4 at (-20, +18) through the 4 mm lid | two insulated pigtail leads only; connector body stays outside | **COUPON REQUIRED** | Test 5x3 / 6x4 / 7x5 and select the smallest damage-free fit |
| **Pigtail strain relief (current source)** | connector body outside; leads tied to existing internal shell post | plug force must not reach ESP32/lid | **DESIGN FIXED / PHYSICAL TEST NEEDED** | Pull-test after selecting the slot and tying the real cable |
| **Docking magnets** | Ø8.4 x 1.2 pockets, 2 per face at y=±14, 4 mm wall | 8 x 1 mm NdFeB discs — **measured, in hand** | **FITS** | Only re-confirm the newly bought batch is the same 8x1 |
| **Nav buttons — cap stem** | Ø3.8 stem projects **4.5 mm behind** the flange through a Ø4.2 hole | must cross a 4 mm wall | **FITS (nominal)** | Stem reaches 0.5 mm inside; 0.4 mm diametral clearance allows resin-in-PETG sliding |
| **Nav buttons — switch reach** | The 6 mm switch body is stopped by the pod's inner front wall; cage back wall takes press load | plunger must meet the stem | **FITS (nominal)** | The front wall is the forward datum; bench-test the actual switch's plunger before final resin batch |
| **6x6x5 tactile switch in cage** | 6.4 mm slot, 7.2 mm depth, legs vertical | 6.0 x 6.0 x 5.0 body [SPEC] | **FITS** | Body and revised cap reach fit on the nominal switch geometry |
| **Dot insert into top plate** | body 11.0 into 11.2 opening; flange 15.0 into 15.2 rebate; heights 2.0 / 1.2; glue shelf 2.0 mm wide, 105.6 mm² | resin tile printed from the same file | **FITS** | Verified numerically. Only risk is FDM square holes printing undersize |
| **Base-plate standoffs** | Ø6 posts at x=±26, plate half-length 28 → 1 mm hangs off the edge | supported footprint | **UNVERIFIED / cosmetic** | Prints as a small unsupported overhang; not structural |

---

## Required outer-box changes — handout checklist

These items are deliberately **not** applied to `outer_box.scad` yet. They either require
the real motor dimensions or a hardware-choice decision; changing them from catalogue
numbers would simply move the fit failure somewhere else.

| Priority | Required change | Why | Prerequisite |
|---|---|---|---|
| Blocker | Re-derive `base_plate_z` and the motor-height allowance | The current 41 mm motor-face height is an unmeasured assumption. It controls the cam/linkage vertical stack. | Measure the actual motor can height and shaft height. |
| Blocker | Redesign the base-plate spring cavity around both motor ears | The right motor screw opens into the existing 22 × 16 mm through-window, leaving a one-screw mount. | Measure the actual motor mounting-ear envelope and hole centres. |
| Blocker | Widen/reposition the base-plate support footprint if the motor-ear fix needs it | The left ear currently has only a 0.35 mm edge wall and the base standoffs overhang the plate by 1 mm. | Motor-ear measurement, then confirm the revised plate still clears the 60 mm shell cavity and corner bosses. |
| Required before installing the owned Hall module | Add a real Hall-module bracket in the outer-box electronics area, or commit to a measured bare-sensor design | The current base-plate pocket is entirely subsumed by the cam pocket and cannot hold the owned module. | Decide module versus desoldered sensor; measure its footprint and sensing-face offset. |
| Decision required | Remove/relocate the four future-muscle-board bosses when using the ULN2003 module | A 35 mm-wide ULN2003 can collide with the y=±19 mm bosses in the outer-box electronics pocket. | Measure the actual ULN2003 board and choose prototype driver versus future muscle PCB. |

**Do not alter the 68 × 68 mm shell, docking windows, magnet pockets, or 4 mm walls as part of
this repair.** Those features are independent of the motor and have already been physically
fit-tested. The next safe sequence is: measure hardware → update the dependent base/mid/cam/
outer-box dimensions together → render the full assembly → print a cheap proving part.

---

## 2. HALL SENSOR — FAILS, twice over

### 2a. The pocket does not physically exist

**[SCAD]** `base_plate.scad`:

- `hall_pocket_h = 3`, cut from `base_thickness - hall_pocket_h` = **z = 2** upward.
- `cam_pocket_depth = 3`, `cam_pocket_diameter = 46`, cut from **z = 2** upward, radius 23.
- Hall pocket footprint: x ∈ [-2.65, +2.65], y ∈ [17.85, 22.15]. Its farthest corner is at
  radius √(2.65² + 22.15²) = **22.31 mm < 23 mm**.

The hall pocket lies **entirely inside the cam pocket, at exactly the same depth**. Subtracting it
removes nothing. There is no rectangular recess on the printed part — just flat cam-pocket floor.

Worse: the cam disc's underside *sits on that floor* (`cam_flat_z = 45`, disc floor 2 mm, pocket
floor z=43 in box coordinates). There is **zero vertical space** above the "pocket" for any sensor,
bare TO-92 or otherwise. The wire channel (`hall_wire_w=2 x hall_wire_d=1`) does survive, but only
in the strip of plate outside r=23.

### 2b. The module is far too big anyway

**[ASSUMED — MEASURE THIS]** The blue MH-Sensor-Series / KY-024-style board Mridul owns (identified
by Codex on 2026-06-03 as an analog+digital module with AO/DO/GND/VCC) is a PCB in the region of
**15 x 11 mm, ~1.6 mm thick, plus a 4-pin 2.54 mm header adding roughly 8-11 mm of height**. Those
figures are typical for that family of modules; they are **not** measured from his part.

Against a 5.3 x 4.3 x 3.0 pocket sized for a bare SS49E/A3144 TO-92 body:

- length: needs ~15, has 5.3 → **~10 mm short**
- width: needs ~11, has 4.3 → **~7 mm short**
- height: needs ~10-13 with the header, has 3 (and really has 0, see 2a) → **hopeless**

### Fixes, in order of preference

1. **Desolder the bare sensor from the module** (recommended). The MH-series board carries a
   standard TO-92 hall device plus an LM393 comparator, an LED and a trimpot. Unsolder the three
   legs, mount the bare TO-92 in the plate, and run three wires back to the module (or straight to
   the ESP32 with a pull-up, since the breadboard test already ran the analog output at 3.3 V).
   This keeps the CAD footprint honest — but §2a still has to be fixed first, because the pocket
   currently isn't there.
2. **Move the module off the base plate entirely.** Mount it on the electronics-pocket floor or on
   a wall of the outer box, with the sensing face pointing up at the cam, and run wires. The cam
   magnet is 3 mm dia — flux falls off fast, so this only works if the module can get within a few
   mm of the magnet path. This is the lowest-CAD-risk option but needs a new bracket.
3. **Enlarge and deepen the pocket.** Requires all three of: (a) make `hall_pocket_h` > 3 so the
   pocket floor drops below the cam pocket floor (e.g. 4.0-4.5 mm, leaving 0.5-1.0 mm of plate
   underneath); (b) grow `hall_pocket_w/d` to the measured module footprint + 0.4 mm; (c) move
   `hall_pocket_y` outboard past y=23 so it is no longer under the disc, **or** add a header
   escape slot. Note the plate is only 5 mm thick and the +Y edge is at y=25 — there is very
   little room. Option 1 or 2 is more realistic.

### 2c. BONUS DEFECT FOUND — the cam homing-magnet pocket is a hole through two tracks

**[SCAD]** `braille_cam.scad`: `magnet_dia=3.0`, `magnet_depth=2.0`, cut as
`cylinder(d=3.2, h=3)` from z=-1, i.e. **z = -1 .. +2**, at r = 17.35, angle 90°.
The disc floor is `disk_base_thickness = 2.0`, spanning z = 0 .. 2.

The cut therefore removes the **entire floor thickness** — it is a through-hole, not a pocket
("leaves 0mm floor" is even in the comment). And at r = 17.35 ± 1.6 it spans r = 15.75 .. 18.95,
which overlaps **track 2** (r 15.4-17.0, drives dot 1) and **track 3** (r 17.1-18.7, drives dot 2).

Where those tracks are in their DOWN state the cam surface at that angle is simply **missing** —
a Ø3.2 mm hole in a running surface that a 1.0 mm-thick linkage foot crosses once per revolution.
The foot will drop in and jam.

**Fix:** shrink `magnet_depth` to ~1.4 mm and thicken the local floor, or (better) move
`magnet_radius` inboard to r < 12 (inside `inner_radius`, under no track at all) and move the hall
sensor to match. Moving the magnet inboard also weakens coupling, so re-check the sensor gap.
Also: **the 3x2 mm homing magnet is not in hand** (`docs/SOURCING.md` §2) — it still has to be bought.

---
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

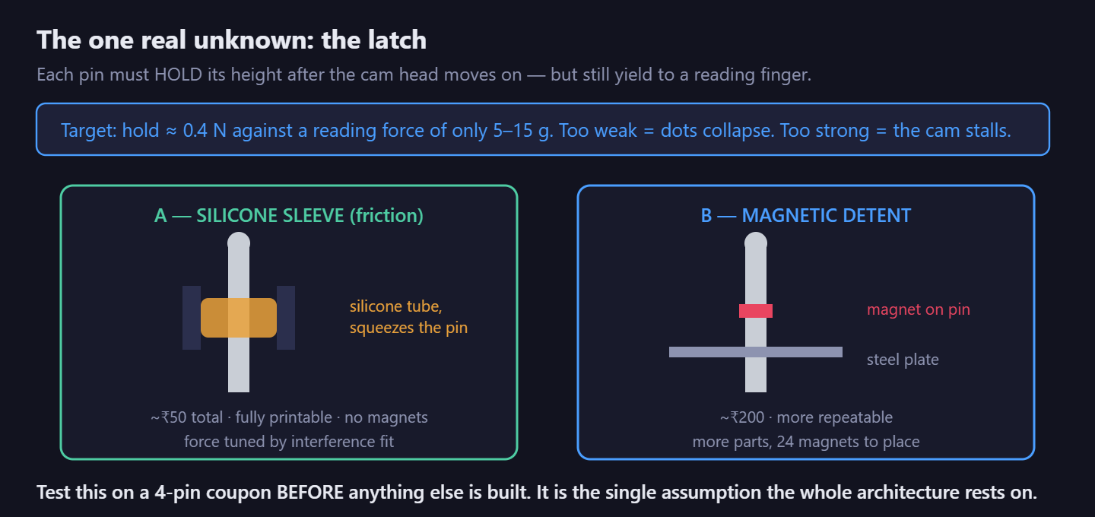
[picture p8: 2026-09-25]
docs/img/latch_concept.png

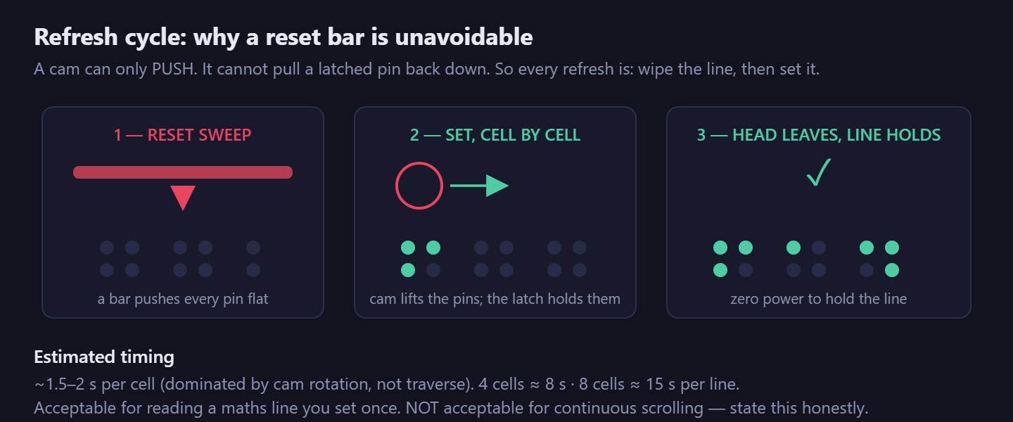
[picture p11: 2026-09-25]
docs/img/refresh_cycle.png

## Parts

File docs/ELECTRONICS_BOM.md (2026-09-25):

# Braillix — Electronics BOM (HAVE on top, BUY at bottom)
> Written 2026-07-30. Companion to `docs/MASTER_BOM.md` (which also covers mechanical parts).
> Scope: **one working single-cell demo.** Multi-cell/production parts are listed separately
> at the end so they are not confused with what you need now.

---

## The headline: you need NO chips, NO resistors, NO capacitors

Every discrete component the circuit would normally need is **already built into the modules
you own**:

| What you'd normally add | Why you don't need it |
|---|---|
| Motor flyback diodes | **Built into the ULN2003A.** The chip has internal freewheeling diodes on its COM pin — that is what COM is for. |
| Motor driver transistors | **That IS the ULN2003.** Seven Darlington pairs, 500mA each. You need four. |
| Button pull-up resistors | ESP32 has **internal** pull-ups. Firmware uses `INPUT_PULLUP`. |
| Hall sensor pull-up / comparator | ⚠️ **Superseded 2026-08-21.** The MH module is dropped. A bare **A3144** is an open-collector switch and needs one external **10k pull-up to 3.3V**. There is no comparator and nothing to trim. |
| Voltage regulator + decoupling caps | **On the ESP32 DevKit already** (AMS1117 + caps). |
| Reverse-polarity protection | ⚠️ **NOT present** in the circuit. Mitigated by measurement: the owned jack was tested and is correct. Measure any new connector before trusting it. |

**Total passives to buy for the demo: zero.**

---

# PART 1 — WHAT YOU ALREADY HAVE
*Cross-check each of these physically. The "how to identify it" column is so you can confirm
you actually have the right thing.*

| # | Component | How to identify it | Qty | Status |
|---|---|---|---|---|
| 1 | **ESP32 DevKit (USB-C)** | Black PCB ~51×28mm, silver square shield, USB-C at one end, 15 pins per side, BOOT + EN buttons | 1 | ✅ HAVE (₹350) |
| 2 | **28BYJ-48 stepper motor** | Silver can ~28mm dia, blue plastic base, 5 coloured wires into a white plug | 1 | ✅ HAVE (₹160 w/ driver) |
| 3 | **ULN2003 driver board** | Small **blue** PCB, 4 red LEDs, white 5-pin socket, black 16-pin chip, IN1–IN4 + `+`/`-` pins | 1 | ✅ HAVE — **this is your motor driver, no chip to buy** |
| 4 | **A3144 unipolar Hall switch, bare TO-92** | Black 3-pin transistor-shaped part, flat face marked A3144 | 10 | 🔴 **BUY (~₹80)** — replaces the MH module (2026-08-21). Digital, self-calibrating, and the CAD pocket already fits it: pocket 4.5×3.5mm vs body 4.1×3.0mm. Needs VCC ≥4.5V, so run it from **5V**, not 3.3V. |
| 5 | **5V / 3A power adapter** | Wall plug, barrel connector on the lead, "5V 3A" on the label | 1 | ✅ HAVE (₹160 w/ jack) |
| 6 | **Inline female DC pigtail jack** | Black cylindrical barrel socket with red/black wires; no thread or nut | 1 | ✅ HAVE / CURRENT POD CHOICE; body stays outside, leads pass through the selected lid slot, internal tie post carries pull load. ✅ Polarity measured correct 2026-08-01 (red = +). |
| 6b | **5.5×2.1mm female panel-mount jack** | Threaded neck plus retaining nut | 0 | ⛔ NOT REQUIRED for the current inline-pigtail revision |
| 7 | **Connecting wire (2m)** | Loose hookup wire | 2m | ✅ HAVE (₹20) |
| 8 | **Dupont jumper wires** | Ribbon of coloured wires with plastic pin housings | some | ✅ HAVE — need ~8× M-F and ~5× M-M |
| 9 | **Neodymium magnets 8×1mm** | Small silver discs, strongly attract each other | 10 | ✅ HAVE (₹135) — for docking, **not** for cam homing |
| 10 | **Tactile switches 6×6×5mm** | Tiny square black buttons, 4 legs | 3 | ✅ HAVE — not needed for the demo |
| 11 | **Digital multimeter** | Handheld meter with DC volts | 1 | ✅ HAVE (bought 2026-08-01) — jack polarity measured and CONFIRMED correct |

### Notes on things you already have

**#6 — ✅ polarity is VERIFIED CORRECT (2026-08-01).** Measured with the multimeter: **red = positive.**
This retires the single largest risk to the ESP32. Mark the positive wire physically (nail polish,
marker, tag) so the information cannot be lost at the bench.
There is still no reverse-polarity protection in the circuit, so if this connector is ever replaced, the replacement must be
measured the same way before it is trusted.

**#4 — your whole Hall module does not fit the base plate.** v7.5 rebuilt an underside pocket for
the *bare* TO-92 sensor only; the blue PCB is still far too large. M11b measures 1.6mm and the
current recess is exactly 1.6mm, so dry-fit it before gluing. **For the demo this does not matter**
— the module sits on the breadboard. For final assembly, desolder the bare 3-pin sensor from the
module and run three wires back to it.

---

# PART 2 — WHAT YOU NEED TO BUY

## 2A. For the demo (buy this week)

| # | Component | Spec | Why | Est. ₹ |
|---|---|---|---|---|
| 1 | **Soldering station, 60W, TEMPERATURE-CONTROLLED** | "936" type, ceramic heater, 2.4mm chisel tip | 🔴 **NOT OWNED.** ⚠️ Do NOT buy a plain ₹200 pencil iron — uncontrolled heat burns the flux off and makes soldering feel impossible. See `ELECTRONICS_PLAN.md` Part 9. | ~1,300 |
| 2 | **Breadboard** | Half-size or full-size, 400–830 tie points | The whole Tier-0 demo is breadboard-based, and it's the safe way to bring up wiring before soldering. | ~100 |
| 3 | **USB-C cable (DATA)** | Must carry data, not charge-only | To flash the ESP32. Charge-only cables look identical and fail silently. **Test the one you have first — you may already be fine.** | ~150 |
| 4 | **Solder wire** | **0.8mm, 60/40 rosin core** | For soldering wires flat to the ULN2003. Not plumbing solder. | ~150 |
| 5 | **Wire stripper / cutter** | Small, for 22–26 AWG | Prepping wire ends. | ~200 |

**Demo subtotal: ~₹1,900** (or ~₹1,750 if your existing USB-C cable does data).
The soldering station is the bulk of it and is the one genuinely missing tool.

## 2B. For the mechanism (buy when the resin parts arrive)

| # | Component | Spec | Qty | Est. ₹ |
|---|---|---|---|---|
| 6 | **Micro compression springs** | **2.0mm OD**, ~0.3mm stainless wire, ~4mm free length. Buy an assortment kit. 🔴 Pen springs (4mm) **cannot** work — braille rows are 2.6mm apart. | 6 + spares | ~500 |
| 7 | **Homing magnet** | ⚠️ **CHANGED 2026-08-21 — now 8mm dia × 1mm thick.** 3×1mm cannot be sourced; the only 3mm stock is 3×3mm, which needs a 3.2mm pocket in a 2.0mm disc floor and fails the cam's own assert. 8×1mm needs 1.2mm and leaves 0.8mm of floor, exactly as 3×1 did. **You already own these.** 🔴 Blocked on CAD: `mech_layout.scad homing_mag_dia` is still 3.0. | 1 (own 10) | ₹0 |
| 8 | **M2.5 × 25mm bolts** | Top plate → standoffs → box bosses | 4 | ~60 |
| 9 | **M4 × 5mm or 6mm thread-forming screws** | Candidate range for the approved raised-stack design. Select the pilot with `base_interface_coupon`; measure the real ear and screw point; require ≥0.5mm clearance below the cam. **Never use M4×10.** No nuts. | 2 | ~30 |
| 10 | **M2 × 8mm self-tap** | Pod lid. **NOT M2×6** — through a 4mm lid that leaves only 2mm of thread. | 2 | ~40 |
| 11 | **Superglue or 5-min epoxy** | Glues the resin dot insert into the PETG plate. Epoxy preferred — you get time to seat it square. | 1 | ~80 |
| 12 | **Digital calipers** | 150mm digital | Already in hand; M5, M11b, and M21 recorded on 2026-07-31. | 1 | already owned |

**Mechanism subtotal: ~₹1,430**

## 2C. Optional / nice to have

| Component | Why | Est. ₹ |
|---|---|---|
| **Hot glue gun + sticks** | ⭐ Strain relief on every joint. **Reworkable** — this is why it beats epoxy while the pin map can still change. See `ELECTRONICS_PLAN.md` Part 12. | ~250 |
| **Neutral-cure RTV silicone** | Optional upgrade over hot glue for vibration. 🔴 Must say **neutral cure** — the vinegar-smelling acetic kind corrodes copper. | ~150 |
| Flux paste | Makes soldering to ULN2003 pins much easier for a beginner | ~100 |
| Helping-hands / third hand | Not really optional — you cannot hold iron, solder and two wires with two hands | ~200 |
| Brass wool tip cleaner | Better than the wet sponge; keeps the tip alive | ~100 |
| Heat-shrink tubing | Insulating soldered joints | ~80 |
| Tweezers | Handling 2mm springs and 1mm linkages — genuinely hard without | ~80 |
| Desoldering pump/wick | Fixing bridges; also for lifting the TO-92 off the hall module | ~120 |
| Small drill bits 1.5/1.7/2.5mm | FDM holes print 0.2–0.3mm undersize | ~150 |
| Electrical tape | — | ~30 |

## 2D. Cost of each ADDITIONAL cell (the scaling claim, priced)

You are building two. This is what a third, fourth or eighth costs — no custom parts at any
point. Full architecture in `ELECTRONICS_PLAN.md` Part 5.

| Per extra cell | Est. ₹ |
|---|---|
| 28BYJ-48 motor + ULN2003 board | ~160 |
| Hall sensor module | ~50 |
| **MCP23017 expander (DIP-28)** + 3 address jumpers | ~90 |
| Wire, connector, heat-shrink | ~50 |
| **Total per cell** | **~₹350** |

**One-off, only when you go past 2 cells:** 2× 4.7kΩ pull-ups (~₹5, brain end only).
**One-off, only past 16 cells:** TCA9548A I²C mux (~₹120).

⚠️ Cells 1 and 2 run **direct-GPIO** and need no expander at all — but building both muscle
boards with the expander anyway is what makes the N-cell claim demonstrable rather than
theoretical.

---

## Totals

| | ₹ |
|---|---|
| Already spent (incl. multimeter) | ~1,435 |
| Demo essentials (2A) | ~1,900 |
| Mechanism (2B) | ~1,430 |
| Optional (2C) | ~960 |
| **Everything** | **~5,725 of ₹15,000** |
| *each cell beyond the 2nd (2D)* | *~350* |

**The breadboard demo needs NO soldering at all** — only the breadboard and a data cable
(~₹250). The soldering station is required to *assemble* a cell, not to demonstrate one.

---

# PART 3 — NOT NEEDED (so you don't buy it by mistake)

| Item | Verdict |
|---|---|
| **Any motor driver IC** | ❌ You own it. The chip on the blue board **is** the ULN2003A. |
| **ATmega328P / custom muscle board** | ❌ Never. Multi-cell is solved by an **MCP23017 per brick** (DIP-28, hand-solderable, ~₹80) — see `ELECTRONICS_PLAN.md` Part 5. TQFP-32 at 0.8mm pitch is beyond basic soldering and would need PCBA ordering. |
| **Resistors** | ❌ None for one or two cells. *(From 3 cells: exactly 2× 4.7kΩ I²C pull-ups, **at the brain end only, once, ever** — repeating them per brick kills the bus.)* |
| **Capacitors** | ❌ None **while the ESP32 runs off USB** with the motor on the adapter — both modules and the DevKit carry their own. ⚠️ **One exception:** if you power the ESP32 from the adapter's `VIN` so it shares the motor's rail, keep a **470µF–1000µF electrolytic** on hand against brown-out resets. See `BUILD_PACK.md` 3.2. |
| **Flyback diodes** | ❌ Built into the ULN2003A (that's what COM does). |
| **Level shifters** | ❌ Not needed — hall runs on 3V3, so GPIO34 never sees 5V. |
| **2mm bearing balls** | ❌ Obsolete since v7.1 — the dot is printed as a dome. |
| **Pogo pin connectors** | ⏸️ Deferred. Do not buy from the CAD window alone. Future contacts need >=1A continuous at working compression (prefer 2-3A for power) and a flush measured carrier; the four-wire bus also needs a per-cell 3.3V expander interface. |
| **Crystal / oscillator** | ❌ ESP32 and the modules have their own. |

---

## If you ever DO build the custom muscle board

Not needed now, but for the record — it's `pcb/braillix_muscle_board.kicad_pcb`, 34×44mm:

| Part | Package | Note |
|---|---|---|
| ATmega328P-AU | **TQFP-32, 7×7mm square** | 0.8mm pitch — **not hand-solderable at your level** |
| ULN2003A | **SOIC-16 rectangle** | Same chip you already own, just SMD |
| 16MHz crystal | HC49 | |
| 2× 22pF, 2× 100nF | 0402 | Tiny — 1.0 × 0.5mm |
| 100µF/10V | SMD electrolytic | |
| 10kΩ ×2, 4.7kΩ ×2 | 0402 | |
| SS14 Schottky | SMA | ⬅️ *this* is the reverse-polarity protection the prototype lacks |

**Recommendation: order it fully assembled (PCBA) or don't build it.** 0402 passives and a
TQFP-32 are not a beginner job, and none of it is needed for a working demo.

---

## 🔴 SPRING CORRECTION - 2026-09-01

**Owned:** 2mm OD, 40mm free length, 50 coils, **0.3mm** stainless, set of 10.
Cuts into ten 4mm / 5-coil pieces each - only 12 pieces are needed for two cells.

**These are ~6x too stiff and must not be fitted.** At the installed geometry they
give 2.84 N per dot at rest against a 0.05-0.15 N braille reading force, and load
the cam with 17.1 N - about 87 mN*m of friction against a ~30 mN*m motor.

**Order instead: 2mm OD, 4mm free length, 0.20mm wire** (0.18mm ideal). Roughly
0.47 N per dot. No other dimension changes. See the handoff entry of the same date
for the full derivation and the paired R-07 dependency.

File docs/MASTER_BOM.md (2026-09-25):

# Braillix — Master Bill of Materials

> **Supersedes `docs/SHOPPING_LIST.md`** (that file still lists 4mm pen springs and 2mm bearing
> balls — both wrong since v7.1). Buy from this file only.
>
> Scope: **1 Brain Pod + 1 Cell**, enough to make one dot go up and come back down.
> Budget ₹15,000 · already spent ₹935 (J.B. Enterprises).
>
> Fastener quantities are **derived from the `.scad` sources and verified**, not estimated —
> each row names the feature it serves. Prices are realistic Indian estimates (Amazon.in /
> robu.in / local market), marked **~** where not quoted from a specific listing.

---

## Status legend
| | Meaning |
|---|---|
| ✅ **HAVE IT** | Already owned — from the ₹935 bill or stated in hand |
| ❌ **NEED TO BUY** | Not owned. Where + estimated cost given |
| ⚠️ **HAVE BUT WRONG** | Owned, but the wrong spec or not enough |

---

## 1. Electronics

| Component | Status | Action Needed |
|---|---|---|
| ESP32 DevKit V1 (30-pin, USB-C) | ✅ HAVE IT | — |
| 5V/3A power adapter | ✅ HAVE IT | — |
| Inline female DC pigtail jack | ✅ **HAVE / CURRENT POD CHOICE** | Connector body remains outside; only the red/black leads pass through the lid slot and are strain-relieved on the internal tie post. Polarity measured correct 2026-08-01, red = positive. Prove slot size with `pigtail_slot_coupon.gcode`. |
| Threaded 5.5×2.1mm female panel-mount jack | ⛔ **NOT REQUIRED FOR THIS REVISION** | The old guessed panel-jack cradle was removed. Reconsider only in a future enclosure redesign. |
| 28BYJ-48 stepper motor (5V) | ✅ HAVE IT / MEASURED | Fit-critical caliper readings recorded, including M5=3.0mm. Vertical stack still needs one coordinated CAD pass. |
| ULN2003 driver module | ✅ HAVE IT | Nominally fits the 14mm pocket **only** with wires soldered flat (~12mm). Vertical Dupont headers will not fit; final board/tail measurement and retention are still required. |
| Hall sensor — MH-Sensor-Series (blue module) | ⚠️ **HAVE BUT WRONG FORM FACTOR** | The whole blue PCB will not fit. v7.5 provides a **4.5 × 3.5 × 1.6mm underside pocket** for its bare TO-92 sensor. M11b is exactly 1.6mm, so dry-fit before gluing. Desolder the sensor and run three wires back; use analog AO behavior for homing. |
| Neodymium magnets 8×1mm (docking) | ✅ HAVE IT | 10 purchased. 4 needed per cell (2 per ±X face). |
| Homing magnet **3×1mm** (for the cam) | ❌ NEED TO BUY | 1 per cell. The blind pocket is 1.2mm deep and leaves 0.8mm of cam floor. An 8×1mm docking magnet is too wide. |
| Tactile switches 6×6×5mm | ✅ HAVE IT | 3 needed (pod nav buttons). Not required for a Tier-0 demo. |
| Female header strips 1×15 | ❌ NEED TO BUY | 2 for the pod DevKit mount. ~₹40. Not needed for a breadboard demo. |
| USB-C cable (data, not charge-only) | ❌ NEED TO BUY / verify | Must carry **data**. Many charge-only cables look identical and silently fail to flash. ~₹150. |
| Resistors / capacitors | ✅ **NOT NEEDED** | 4.7k I²C pull-ups are only for the multi-cell I²C bus, which is not in the demo. No protection parts needed for a single cell. |
| Pogo pin connectors | ⏸️ **DEFERRED** | Do not buy yet. Require a measured flush carrier and >=1A/contact continuous (prefer 2-3A for power). The four-wire architecture also needs a per-cell 3.3V expander interface. |

## 2. Mechanical & fasteners
*Counts derived from the SCAD sources and verified against them.*

| Component | Qty | Status | Serves / Action |
|---|---|---|---|
| **M2.5 × 25mm bolts** | 4 | ❌ NEED TO BUY | `top_plate` counterbores → `base_plate` standoffs → `outer_box` corner bosses. Verified: 25mm gives ~9.5mm engagement. ~₹60 |
| **M4 motor ear screws** | 0 | ❌ **DO NOT BUY** (2026-08-31) | ⚠️ **The current stack has no motor screws.** The motor dropped onto the box floor on 2026-08-26, so its ears are at z=37 while this plate's pilots are at z=41 — 4mm apart, no screw can span them. `base_plate.scad` records this as deliberate: the seat carries the load and the wire block carries the torque. The earlier M4×5-brass line is withdrawn; the brass argument is also moot, because there is no longer a steel screw near the magnet orbit. Revisit only if retention bosses come back in the R-07 pass. |
| **M2 × 8mm self-tap** | 2 | ❌ NEED TO BUY | Pod lid → shell bosses. 🔴 **NOT M2×6** — through a 4mm lid that leaves only **2mm** of thread; 8mm gives 4mm. Verified. ~₹40 |
| M2 × 6mm self-tap | 4 | ⏸️ DEFERRED | Muscle-board bosses. Not used in the prototype (ULN2003 sits on the pocket floor). |
| **2mm OD micro compression springs** | 6 + spares | ❌ NEED TO BUY | 🔴 **CRITICAL, no substitute.** 2.0mm OD, ~0.3mm stainless wire, ~4mm free length. Pen springs (4mm) **cannot** work — braille rows are 2.6mm apart. Buy an **assortment kit** (200–400pcs) so you're not betting on one guess. ~₹500 |

## 3. Consumables

| Component | Status | Action Needed |
|---|---|---|
| Solder wire | ❌ NEED TO BUY | **0.8mm, 60/40 rosin-core.** Not plumbing solder. ~₹150 |
| Flux paste | ❌ NEED TO BUY | Not strictly required, but makes soldering to ULN2003 pins far easier for a beginner. ~₹100 |
| Superglue (CA) **or** 5-min epoxy | ❌ NEED TO BUY | Glues the resin `dot_insert` into the PETG top plate, and the magnets. **Epoxy recommended** — it gives you time to seat the tile square. ~₹80 |
| Heat-shrink tubing (1–3mm assorted) | ❌ NEED TO BUY | Insulating soldered joints. ~₹80 |
| Electrical tape | ❌ NEED TO BUY | ~₹30 |
| Silicone grease | ❌ NEED TO BUY | Cam tracks, to reduce stall risk. A tiny amount. ~₹80 |
| Dupont jumper wires | ✅ HAVE IT | 2m wire + spares purchased. For counts see below. |
| Breadboard | ❌ NEED TO BUY | **Yes, still needed** — the Tier-0 demo is breadboard-based, and it is the safest way to bring up wiring before anything is soldered. Half+ size. ~₹100 |

**Dupont counts for the demo wiring** (13 connections total): **M-F ×8** (ESP32 header → breadboard/module), **M-M ×5** (rail to rail, module to rail). F-F not needed. If your 2m wire is bare, you need crimps or you solder directly.

## 4. Tools

| Tool | Status | Action Needed |
|---|---|---|
| Soldering station | ❌ **NEED TO BUY** | 🔴 **Not owned** (an earlier revision of this file wrongly said it was). Buy a **60W temperature-controlled "936" station with a 2.4mm chisel tip**, ~₹1,300 — NOT a plain ₹200 pencil iron. Full reasoning in `ELECTRONICS_PLAN.md` Part 9. |
| **Digital multimeter** | ✅ **HAVE IT** (bought 2026-08-01) | Jack polarity measured and **confirmed correct** — red = positive. The largest single risk to the ESP32 is retired. |
| **Digital calipers** | ✅ **IN HAND / USED** | Motor, Hall thickness, and ESP32 row-pitch readings recorded on 2026-07-31. |
| Wire stripper / cutter | ❌ NEED TO BUY | ~₹200 |
| Desoldering pump or wick | ❌ OPTIONAL | Useful if you need to lift the TO-92 off the hall module, or fix a bridge. ~₹120 |
| Tweezers | ❌ OPTIONAL | Strongly recommended for 2mm springs and 1mm linkages. ~₹80 |
| Small drill bits (1.5/1.7/2.5mm) | ❌ OPTIONAL | FDM holes print 0.2–0.3mm undersize; these clean them out. ~₹150 |

### Soldering difficulty — the honest read
**Nothing in the demo build requires fine-pitch work.** The hardest joint is soldering wires flat
onto the ULN2003's 2.54mm header pads — comfortably within basic skill.

The **only** fine-pitch work in the whole project is the custom muscle board (TQFP-32 at 0.8mm
pitch, SOIC-16, 0402 passives). That is **beyond basic soldering** — order it assembled (PCBA)
or stay on the ULN2003 module. It is not needed for the demo either way.

---

## 5. What to actually spend

| Path | Contents | Cost |
|---|---|---|
| **🎯 Cheapest working demo** | multimeter, breadboard, solder wire, strippers, USB-C cable | **~₹1,100** |
| **+ mechanism** | above + springs, homing magnet, fasteners, glue, calipers | **~₹2,900** |
| **Everything in this BOM** | all of the above + optional tools + consumables | **~₹3,900** |

**Project total if you buy everything: ₹935 + ~₹3,900 = ~₹4,835 of ₹15,000.** Comfortable.

> **Deliberately excluded: the resin print order.** Do the cheap PETG proving print and make one
> dot move *before* spending on resin. Every downstream decision rests on a mechanism that has
> never been physically tested.

---

## 6. Buy these first (this week)

1. **Multimeter** (~₹500) — unblocks safe power-up. Nothing else can happen safely without it.
2. **Breadboard + USB-C data cable + solder wire** (~₹400) — everything needed for the Tier-0 demo.
No panel-mount jack is required for the current revision; use the owned pigtail and prove its cable-only slot first.

Calipers are now in hand and the motor, Hall thickness, and ESP32 row-pitch measurements are recorded.

---

## 7. Unverified — measure before buying or printing

| # | What | Feeds |
|---|---|---|
| 1 | Motor vertical stack re-derivation from the completed owned-part readings | `base_plate`, `mid_plate`, cam bore |
| 2 | Smallest pigtail cable slot that passes both insulated leads without damage | `power_cable_slot_w/h` in the pod lid; use the 5x3 / 6x4 / 7x5 coupon |
| 3 | Hall module PCB dimensions (or switch to bare TO-92) | `base_plate` hall pocket |
| 4 | Actual magnet diameter/thickness from the bill | dock magnet pockets (CAD assumes 8×1mm) |
| 5 | ESP32 board length/width if the catalogue envelope proves tight; pin-row pitch is measured 25.6mm | pod board envelope |
| 6 | Pogo connector, once chosen | `outer_box` pogo carrier pocket |

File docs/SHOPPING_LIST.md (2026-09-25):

> # [!] SUPERSEDED — DO NOT BUY FROM THIS LIST
>
> **Use `docs/MASTER_BOM.md` instead.** This file is kept only for history.
>
> At least two entries here are now WRONG and would waste money:
> * **4mm pen-style springs** — ruled out permanently in v7.1. Braille rows are 2.6mm apart,
>   so a 4mm spring fouls its neighbour. You need **2mm OD micro springs**.
> * **2mm bearing balls** — no longer needed at all since v7.1. The braille dot is printed
>   as a dome on the linkage itself; there is nothing to glue a ball onto.

# Braillix v5.1 — Complete Electronics & Hardware Shopping List

**Assuming: 1 Brain Pod + 1 Cell (prototype). Multiply cell items by N for more cells.**

---

## A. ESP32 BRAIN POD

| # | Item | Specs | Qty | Est. Price | Source |
|---|---|---|---|---|---|
| 1 | ESP32 DevKit V1-compatible (30-pin) | WiFi+BT, **USB-C; use the owned board** | 1 | Already owned | — |
| 2 | Female header strip 1x15 | 2.54mm pitch, through-hole | 2 | Rs 10 each | Local / Robocraze |
| 3 | 5.5x2.1mm inline female barrel pigtail | Use the owned cable; not a panel-mount jack | 1 | Already owned | — |
| 4 | 5V 3A DC adapter | 5.5x2.1mm barrel plug, regulated | 1 | Rs 200 | Local / Amazon |
| 5 | 6x6x5mm tactile push switch | 4-pin DIP, momentary | 3 | Rs 5 each | Robocraze / LCSC |
| 6 | 4.7k ohm resistor (1/4W) | Through-hole or 0805 SMD | 2 | Rs 1 each | Local |
| 7 | Piezo buzzer (optional) | 5V, 12mm | 1 | Rs 15 | Local |

**Pod subtotal: ~Rs 420**

---

## B. PER CELL — Motor + Mechanical

| # | Item | Specs | Qty/cell | Est. Price | Source |
|---|---|---|---|---|---|
| 8 | 28BYJ-48 stepper motor | 5V DC, 4-phase, 64:1 gearbox | 1 | Rs 80 | Robocraze |
| 9 | SS49E Hall effect sensor | Linear, SIP-3, 3-6V | 1 | Rs 25 | Robocraze / LCSC |
| 10 | 3x1mm NeFeB disc magnet | Neodymium, for cam homing | 1 | Rs 5 | Local / AliExpress |
| 11 | 2mm stainless steel bearing balls | For braille dot caps | 6 | Rs 2 each | Local hardware / Amazon |
| 12 | Micro compression spring | OD 4-4.5mm, length 5-6mm | 6 | Rs 3 each | Local hardware |

**Per-cell mechanical subtotal: ~Rs 140**

---

## C. PER CELL — Muscle Board PCB Components

**Option A: Get PCBs fabricated (recommended)**
| # | Item | Qty/cell | Est. Price |
|---|---|---|---|
| 13 | Muscle board PCB (34x44mm, 2-layer) | 1 | Rs 35 (JLCPCB, 5pc MOQ) |

**Option B: Use breadboard/perfboard for prototype**
| # | Item | Qty/cell | Est. Price |
|---|---|---|---|
| 13b | Arduino Pro Mini 5V/16MHz | 1 | Rs 120 |
| 13c | ULN2003 driver board (module) | 1 | Rs 40 |
*Skip to section D if using Option B*

**If fabricating PCBs, you need these SMD components per board:**
| # | Item | Package | Qty/board | Est. Price | LCSC Part |
|---|---|---|---|---|---|
| 14 | ATmega328P-AU | TQFP-32 | 1 | Rs 210 | C14877 |
| 15 | ULN2003A | SOIC-16 | 1 | Rs 25 | C7386 |
| 16 | 16MHz crystal | HC49-4H | 1 | Rs 12 | C32346 |
| 17 | 22pF capacitor | 0402 | 2 | Rs 1 each | Generic |
| 18 | 100nF capacitor | 0402 | 2 | Rs 1 each | Generic |
| 19 | 100uF/10V electrolytic | SMD 5x5.3mm | 1 | Rs 12 | C131307 |
| 20 | 10k ohm resistor | 0402 | 2 | Rs 1 each | Generic |
| 21 | 4.7k ohm resistor | 0402 | 2 | Rs 1 each | Generic |
| 22 | SS14 Schottky diode | SMA | 1 | Rs 4 | C2480 |
| 23 | 1x04 pin header | 2.54mm | 1 | Rs 3 | Cut from strip |
| 24 | JST XH 5-pin connector | B5B-XH-A | 1 | Rs 8 | C2316 |
| 25 | 1x03 pin header | 2.54mm | 1 | Rs 2 | Cut from strip |
| 26 | 2x03 pin header (ISP) | 2.54mm | 1 | Rs 3 | Cut from strip |

**Per-cell PCB subtotal: ~Rs 320 (custom) or Rs 160 (Pro Mini + ULN2003 module)**

---

## D. DAISY-CHAIN / CONNECTORS

| # | Item | Specs | Qty | Est. Price | Source |
|---|---|---|---|---|---|
| 27 | 4-pin pogo connector (spring+pad pair) | 2mm pitch, spring-loaded | N+1 pairs | Rs 40/pair | LCSC / AliExpress |
| 28 | 8x1mm NeFeB disc magnets (docking) | 2 per docking face; 10 owned covers pod + two cells | 10 | Already owned | — |

**Count your magnets carefully:**
- Each cell: 3 on -X face + 3 on +X face = **6 per cell**
- Pod: 3 on +X dock face = **3 for pod**
- Total for 1 pod + N cells: **3 + 6N magnets**
- For 1 pod + 1 cell prototype: **9 magnets**

---

## E. HARDWARE / FASTENERS

| # | Item | Specs | Qty | Est. Price | Source |
|---|---|---|---|---|---|
| 29 | M2.5 x 25mm bolts | Pan head or socket head | 4 per cell | Rs 2 each | Local hardware |
| 30 | M2 x 6mm screws | Pan head | 4/cell (board) + 2 (pod lid) | Rs 1 each | Local hardware |
| 31 | M4 bolts + nuts | ~10mm, for motor mounting | 2 per cell | Rs 2 each | Local hardware |
| 32 | M2 grub/set screw | 3-4mm long (if using comb later) | 1 per cell | Rs 2 | Local hardware |

---

## F. WIRE / SOLDER SUPPLIES

| # | Item | Specs | Qty | Est. Price | Source |
|---|---|---|---|---|---|
| 33 | Hookup wire (stranded) | 22-26 AWG, multiple colors | 1 roll each: Red, Black, Blue, Yellow, Green, White | Rs 30/roll | Local |
| 34 | Heat shrink tubing | Assorted 1-3mm | 1 pack | Rs 30 | Local |
| 35 | Solder wire | 60/40 or lead-free, 0.5-0.8mm | 1 roll | Rs 80 | Local |
| 36 | Flux paste | For SMD soldering | 1 syringe | Rs 50 | Local |
| 37 | Superglue (CA) | For bearing balls onto linkage nubs | 1 tube | Rs 20 | Local |
| 38 | Silicone grease | For linkage feet on cam tracks | 1 small tube | Rs 40 | Local |

---

## G. TOOLS (if you don't have them)

| # | Item | Why | Est. Price |
|---|---|---|---|
| 39 | Soldering iron (temp-controlled) | SMD + through-hole | Rs 500+ |
| 40 | AVR ISP programmer (USBasp) | To flash ATmega328P bootloader | Rs 150 |
| 41 | Multimeter | Continuity, voltage checks | Rs 200+ |
| 42 | Wire stripper | 22-26 AWG | Rs 100 |
| 43 | Small file set | Trim motor shaft to 4mm | Rs 80 |
| 44 | Tweezers (fine tip) | SMD placement + spring insertion | Rs 50 |
| 45 | Calipers (digital) | Measure shaft, pin pitch, etc. | Rs 300 |

---

## COST SUMMARY (1 Pod + 1 Cell prototype)

| Category | Cost |
|---|---|
| Brain Pod electronics | Rs 420 |
| Cell mechanical | Rs 140 |
| Cell electronics (Pro Mini route) | Rs 160 |
| Connectors + magnets | Rs 85 |
| Hardware/fasteners | Rs 30 |
| Wire/solder/glue | Rs 250 |
| **TOTAL (excluding tools + 3D printing)** | **~Rs 1,085** |

For 5 cells + 1 pod: ~Rs 2,500 (well under 15,000 INR budget)

---

## QUICK SHOP LIST (just the names, for the counter)

```
ESP32 DevKit V1 (30-pin) x1
28BYJ-48 stepper motor x1
Arduino Pro Mini 5V/16MHz x1 (or ATmega328P-AU if doing custom PCB)
ULN2003 driver board x1 (or ULN2003A SOIC-16 if custom PCB)
SS49E Hall sensor x1
5V 3A DC adapter with barrel jack x1
Panel-mount barrel jack 5.5x2.1mm x1
6x6x5mm tactile switch x3
4-pin pogo connector pair x2
3x1mm homing magnet x1; 8x1mm docking magnets x10 already owned
2mm bearing balls x6
Micro compression springs (OD 4mm, 5mm long) x6
Female header strip 1x15 x2
Male header strip 40-pin x2 (cut to size)
JST XH 5-pin connector x1
Resistors: 4.7k x4, 10k x2
22pF capacitor x2, 100nF x2, 100uF/10V x1
SS14 Schottky diode x1
16MHz crystal x1
M2.5x25 bolts x4
M2x8 screws x2 (pod lid); M2x6 x4 only if the deferred muscle board is built
M4x5 thread-forming screws x2; no nuts, no M4x6/x10
Hookup wire (Red, Black, Blue, Yellow, Green, White)
Heat shrink assorted
Solder wire
Superglue
Silicone grease
```

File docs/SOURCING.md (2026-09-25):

# Braillix — Hardware Sourcing Guide (India)
> Created 2026-06-12 (v6.1). What to buy, what to search for, what's already in hand.

## ✅ Already in hand (validated)
| Item | Status |
|---|---|
| 28BYJ-48 stepper + ULN2003 driver module | working on breadboard |
| ESP32 DevKit V1 | working, WiFi + OTA tested |
| NeFeB disc magnets **8mm dia × 1mm thick** | plenty — CAD v6.1 pockets sized for these |
| Hall sensor (SS49E-class) | validated (saturates 0/4095, fine for edge homing) |
| 6×6mm tactile switches ×3 | in hand |
| Inline female DC pigtail jack + 5V/3A adapter | in hand; current pod choice; polarity verified red = positive |
| Jumper wires (Dupont) | in hand (housings get cut off for in-cell wiring) |

## 🛒 TO BUY

### 0. Enclosure power connector — no new purchase for this revision

Use the owned inline pigtail. Its body remains outside the pod; only the two leads pass through the
coupon-selected lid slot and tie to the internal strain-relief post. Print
`pigtail_slot_coupon.gcode` before finalizing `power_cable_slot_w/h`. A threaded panel-mount jack is
only a future redesign option.

### 1. Return springs x6 (+ spares) — 2mm OD MICRO springs
**Spec: 2.0mm OD, ~0.3mm stainless wire, ~4mm free length.** One per braille dot.

> ⚠️ **Ballpoint-pen springs CANNOT be used.** They are ~4mm OD and need ~4.2mm of
> spacing; braille rows are only **2.6mm** apart, so a pen spring would overlap the
> spring of the dot above it by 1.4mm. This is geometry, not preference — no nub size
> fixes it. 2mm OD is the largest that fits (0.6mm to spare).

- Search **"micro compression spring 2mm OD"** or **"compression spring assortment kit"**
  on Amazon.in. 2mm/3mm/4mm/5mm/6mm OD in 0.3mm stainless is a standard catalogue range.
- **Buy an assortment kit** (200-400pcs, 15-30 sizes, roughly Rs 400-700) rather than one
  size — it covers us if the free length needs adjusting after the first assembly.
- If a seller offers **0.2mm wire**, prefer it: same OD but a wider bore, which gives more
  clearance around the 1.0mm nub.
- Working range in the design: 3.0mm when the dot is down, 2.2mm when raised. A ~3.5-4.0mm free
  length with ~5 coils is the test range (<=1.5mm solid height, so it never bottoms out).

**Fitting them:** thread each spring over the 1.5mm dome by TWISTING it on (the coil acts
like a thread against the 1.4mm bore — 0.1mm interference, trivial for steel). Then it sits
on the linkage flange and drops into the counterbore in the resin dot insert. Do not glue the spring before the bench test.

**Backup if springs cannot be sourced:** a small disc of **soft open-cell sponge** in place
of each spring. Must be squishy sponge/upholstery/packing foam — **NOT stiff EVA craft
foam**, which is roughly 20x too stiff and risks stalling the motor. Free from packaging.
The printed parts are identical either way, so this can be tested without a reprint.

### 2. Homing magnets 3×1mm ×1 per cell — small but specific
Your 8×1mm magnets are for DOCKING. The cam's homing pocket (`braille_cam.scad`) needs a
**3mm dia × 1mm thick** disc — an 8mm one will not fit and a 2mm-thick magnet destroys the cam floor.
- Search: **"3x1mm neodymium magnet"** on robu.in / Amazon.in — verify the actual thickness.
- Glue flush into the cam underside pocket at r=17.35 (the 90° position).

### 3. ~~Bearing balls 2mm~~ — NO LONGER NEEDED (v7.1)
The braille dot is now **printed as a dome on the linkage itself**. No steel balls, no
glue, no machined cup. If you already bought balls, keep them for something else.

### 3b. Glue for the dot insert (v7.2)
The top plate is now PETG/FDM with a small **resin dot insert** glued into a pocket.
- **CA (superglue) or 5-min epoxy** — either works. Epoxy is more forgiving (you get
  time to seat it square); CA is instant but unforgiving.
- Bead it on the **rebate shelf** (the 2mm-wide ledge, ~106mm² of contact), not on the
  insert. Drop the insert in flange-down; it self-locates.
- **Wipe squeeze-out from the top face before it cures.** If glue reaches the six dot
  holes the domes will jam and the cell is dead.

### 4. Pogo connector (4-pin) — DEFERRED DECISION (per v6 audit)
Don't buy until the electrical architecture and carrier are pinned. A 0.5A/contact part is
insufficient for the aggregate chain. Require >=1A continuous/contact at working compression,
preferably 2-3A on power, and a flush internal carrier. Two candidate styles:
- **Spring-loaded pogo pin strip, 4-pin, 2.54mm pitch** (search "pogo pin connector 4 pin
  2.54mm") — what the CAD windows roughly assume; needs a mating flat-pad part.
- **Magnetic pogo connector module** (search "magnetic pogo connector 4 pin") — combines
  the magnet + contacts in one part; would simplify the dock AND solve the upside-down
  anti-reversal problem at the connector level (these are polarized).
**When the part arrives → measure it → update `pogo_carrier_*` dims in outer_box.scad
before the final print.** Current pocket dims are placeholders.

The four-contact 5V/GND/SDA/SCL bus is future-only: every cell still needs a 3.3V-powered
expander/regulator or explicit level shifting. Tomorrow's direct one-cell build uses the separate
8-wire rear harness, not the pogo window.

### 5. Fasteners (one trip to a fastener shop / one Amazon order)
| Item | Qty (1 cell + pod) |
|---|---|
| M2.5 × 25mm bolts | 4 |
| M2 × 8mm self-tap screws | 2 (pod lid) |
| M2 × 6mm self-tap screws | 4 only if the deferred muscle board is ever built |
| M4 × 5mm thread-forming screws | 2 (motor ears; coupon first; do not use M4×6/x10 without measured clearance) |
*not needed while running the ULN2003-on-floor prototype

### 6. Consumables
CA glue (balls + magnets), silicone grease (cam tracks), heat-shrink, solder.

## 🏭 NOT bought — manufactured
| Item | How |
|---|---|
| Linkages ×8 (6+2 spares) | **Resin print** with the cam/top_plate/nav_cap batch — tough/ABS-like resin, flat on plate (v6.1 decision; was laser-cut metal) |
| Muscle board PCB | Deferred — prototype runs the off-the-shelf ULN2003 module on the pocket floor (see WIRING_AND_ASSEMBLY.md) |

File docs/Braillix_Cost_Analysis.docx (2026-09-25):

Table 1: Cost Analysis

S. No. | Item | Quantity | Cost (Rupees)

A. BRAIN POD ELECTRONICS (2 units)
1 | ESP32 DevKit V1 (USB-C, 30-pin) | 2 | 700
2 | 5 V / 3 A Power Adapter with DC Barrel Jack | 2 sets (+1 spare jack) | 440
3 | USB-C Data Cable | 2 | 250
4 | Pod Interface Parts - tactile navigation buttons, female header strips | 1 set | 120

B. BRAILLE CELL ELECTRONICS (2 cells + spares)
5 | 28BYJ-48 Stepper Motor with ULN2003 Driver Board | 3 (2 + 1 spare) | 480
6 | Hall Effect Sensor Module (MH-Sensor-Series) | 3 (2 + 1 spare) | 150
7 | Neodymium Magnets - homing (3 x 1 mm) and docking (8 x 1 mm) | 20 | 255

C. PROTOTYPING HARDWARE
8 | Breadboard, 830 tie-point | 2 | 200
9 | Wiring Set - Dupont jumpers, hookup wire, screw terminal blocks | 1 set | 260

D. FASTENERS AND SPRINGS
10 | Machine Screws - M2.5 x 25 mm, M4 x 10 mm, M2.5 x 8 mm | 26 (8 used) | 220
11 | Brass Heat-Set Insert Kit (M2 / M2.5 / M3) | 1 kit | 300
12 | Micro Compression Springs, 2 mm OD (assortment kit) | 1 kit (12 used) | 450

E. 3D PRINTING MATERIALS
13 | PETG Filament, 1 kg Spool (enclosure and plates) | 1 | 850
14 | Resin Parts - outsourced SLA print order | 1 order | 900
15 | Failed Print / Reprint Material Allowance | - | 600

F. TOOLS AND CONSUMABLES
16 | Soldering Station, 60 W, Temperature-Controlled | 1 | 600
17 | Soldering Accessories - solder wire, flux, spare tips, tip cleaner, desoldering pump | 1 set | 510
18 | Digital Multimeter | 1 | 450
19 | Digital Vernier Calipers, 150 mm | 1 | 450
20 | Hand Tools - wire stripper, precision tweezers, drill bits | 1 set | 360
21 | Hot Glue Gun with Glue Sticks | 1 | 200
22 | Assembly Consumables - super glue, heat-shrink tubing, insulation tape, silicone grease | 1 set | 300

G. CONTINGENCY AND LOGISTICS
23 | Component Failure Replacement Reserve | - | 500
24 | Shipping and Delivery Charges (online orders) | - | 350
TOTAL | | | 9,895

Table 2: Cost Summary by Category

Category | Amount (Rupees)
A. BRAIN POD ELECTRONICS (2 units) | 1,510
B. BRAILLE CELL ELECTRONICS (2 cells + spares) | 885
C. PROTOTYPING HARDWARE | 460
D. FASTENERS AND SPRINGS | 970
E. 3D PRINTING MATERIALS | 2,350
F. TOOLS AND CONSUMABLES | 2,870
G. CONTINGENCY AND LOGISTICS | 850
Total Project Cost | 9,895
Sanctioned Budget | 10,000
Balance Remaining | 105

Notes

1. Costs are realistic Indian-market estimates (Amazon.in, Robu.in, and the local electronics market). Actual invoiced amounts may vary by supplier.

2. The configuration priced is two Brain Pods and two Braille Cells. The system architecture uses one Brain Pod as the master controller; the second unit is held as a spare, so that a failure of the controller does not stop the demonstration. Quantities in Sections A and B follow from that configuration.

3. Spare units are included for the components most likely to fail in a prototype: the stepper motor with its driver board, the Hall effect sensor, and the DC barrel jack. Fasteners and springs are purchased as kits, so surplus is inherent.

4. Section E covers 3D printing consumables. The reprint allowance reflects material lost to failed prints, which were observed during the first PETG enclosure trials.

5. Section G reserves funds for components damaged during assembly and for delivery charges on online orders. This reserve is included within the total, not additional to it.

6. Committed expenditure, excluding the Section G reserve, is Rs. 9,045.

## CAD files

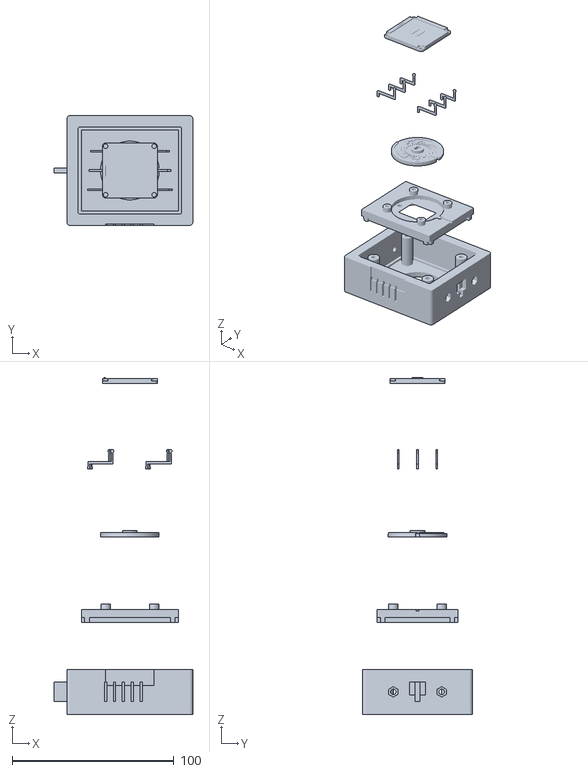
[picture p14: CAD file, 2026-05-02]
renders/braillix_assembly.stl
85.9 x 68.0 x 208.6

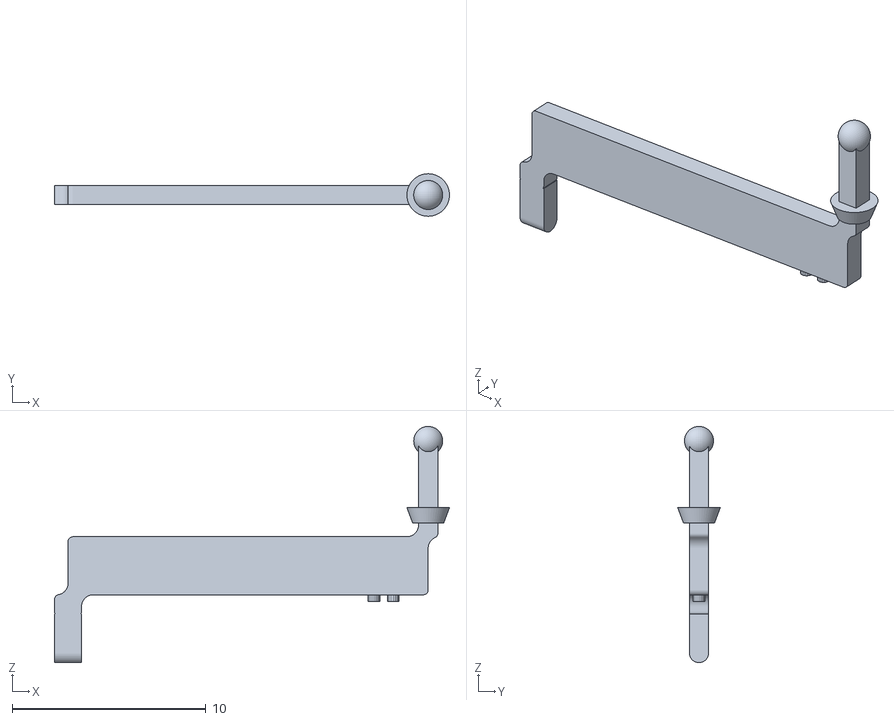
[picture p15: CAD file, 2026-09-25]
cad/stl/linkage_asm_2.stl
20.4 x 2.20 x 12.2

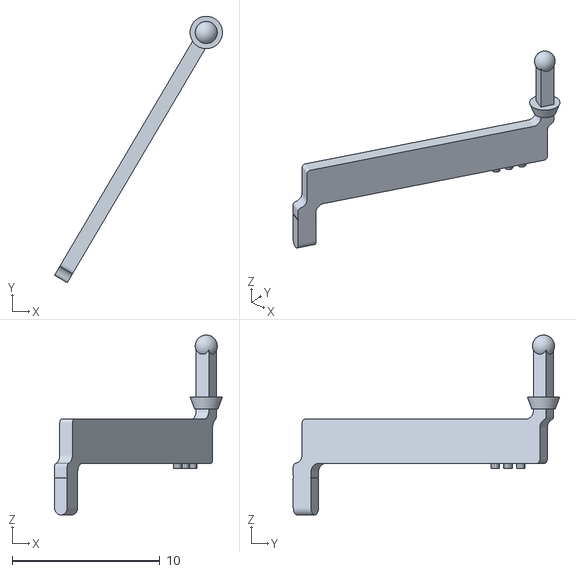
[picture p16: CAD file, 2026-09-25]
cad/stl/linkage_asm_3.stl
11.4 x 18.1 x 12.2

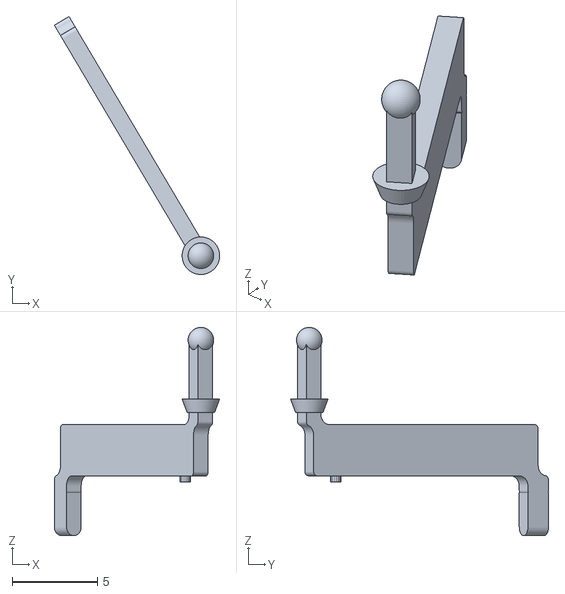
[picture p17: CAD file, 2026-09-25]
cad/stl/linkage_asm_1.stl
9.69 x 15.1 x 12.2

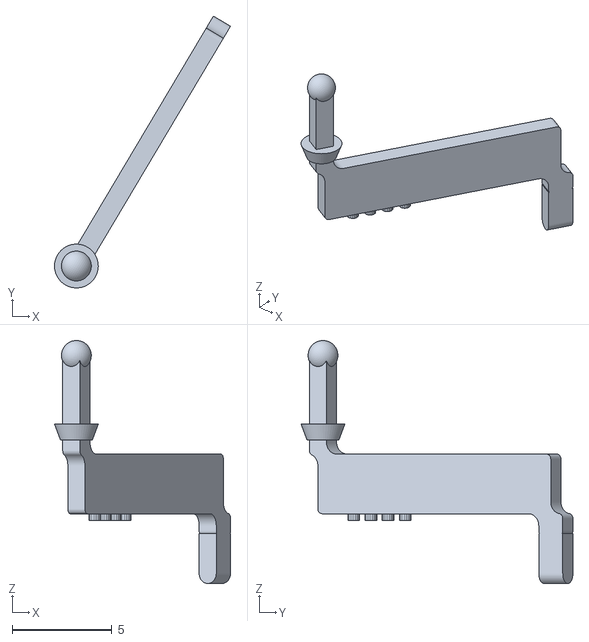
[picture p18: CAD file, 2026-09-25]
cad/stl/linkage_asm_4.stl
8.84 x 13.6 x 12.2

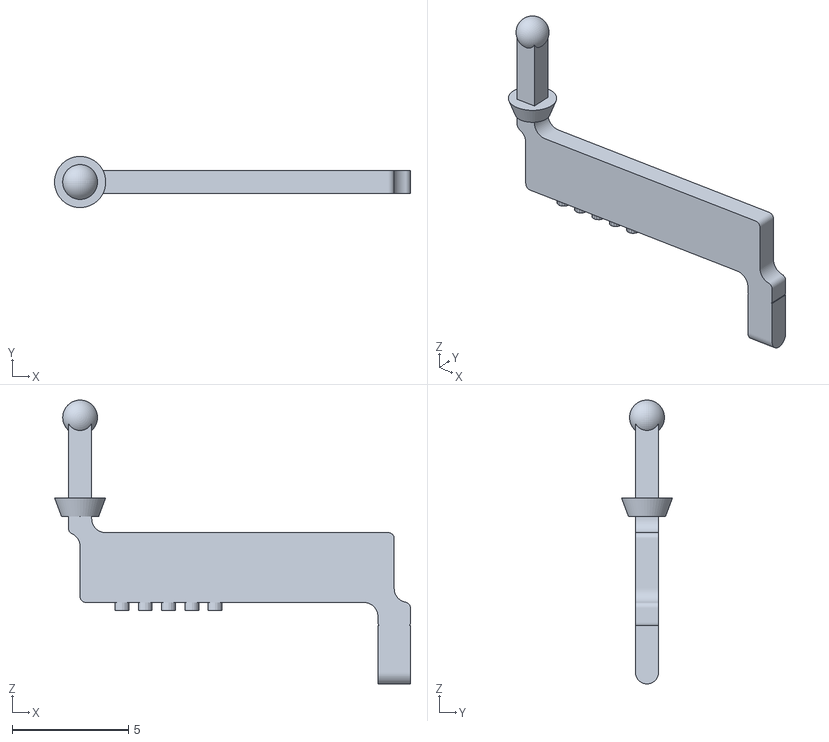
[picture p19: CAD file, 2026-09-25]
cad/stl/linkage_asm_5.stl
15.3 x 2.20 x 12.2

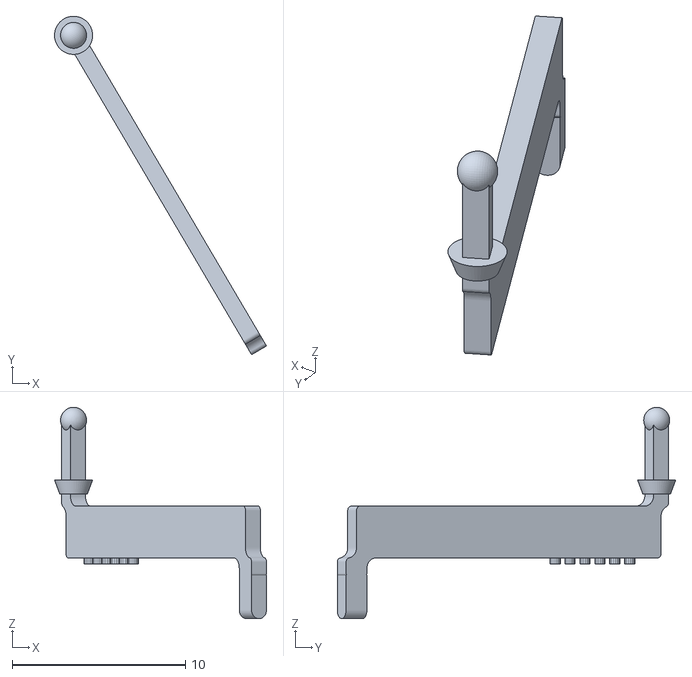
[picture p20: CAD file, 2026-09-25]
cad/stl/linkage_asm_6.stl
12.2 x 19.5 x 12.2

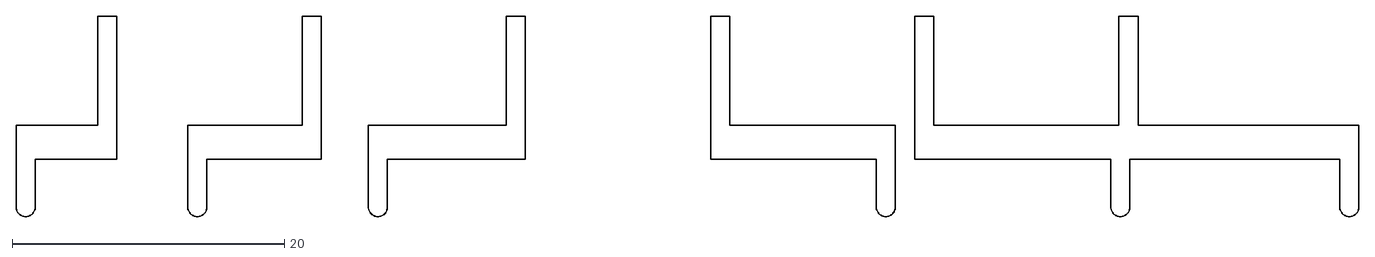
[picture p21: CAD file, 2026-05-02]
cad/dxf/linkage_UNNAMED.dxf
98.6 x 14.7

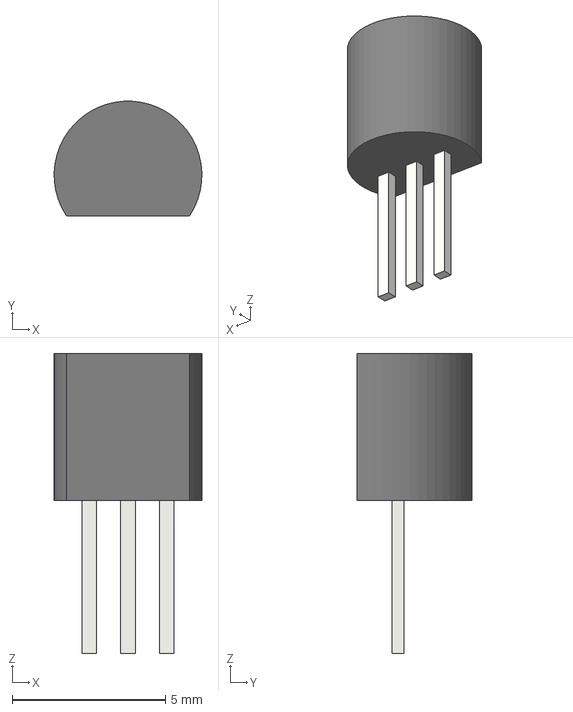
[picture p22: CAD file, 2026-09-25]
cad/models/kicad/TO-92_Inline.step
4.83 x 3.74 x 9.80 mm

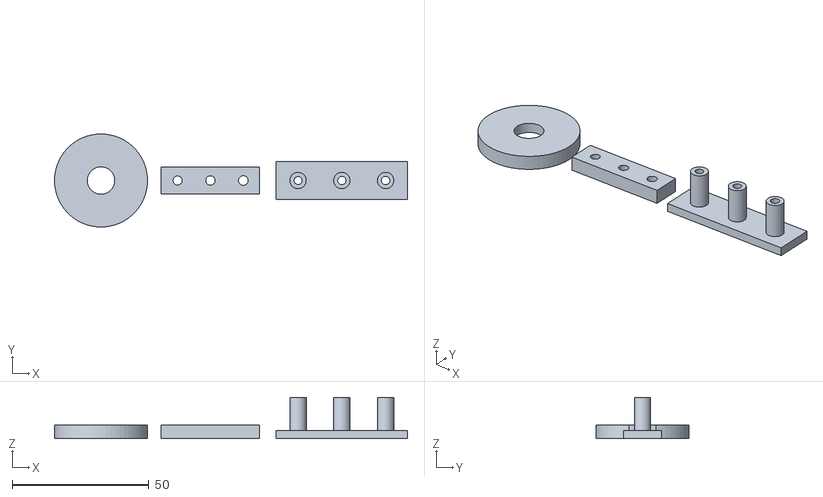
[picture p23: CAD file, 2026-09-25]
cad/stl/base_interface_coupon.stl
129.0 x 34.0 x 15.0

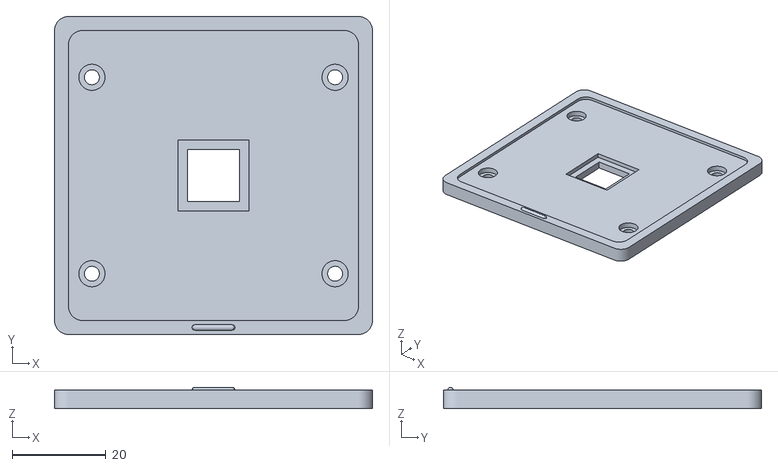
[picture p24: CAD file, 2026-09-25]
cad/stl_option_a_candidate/top_plate.stl
68.0 x 68.0 x 4.59

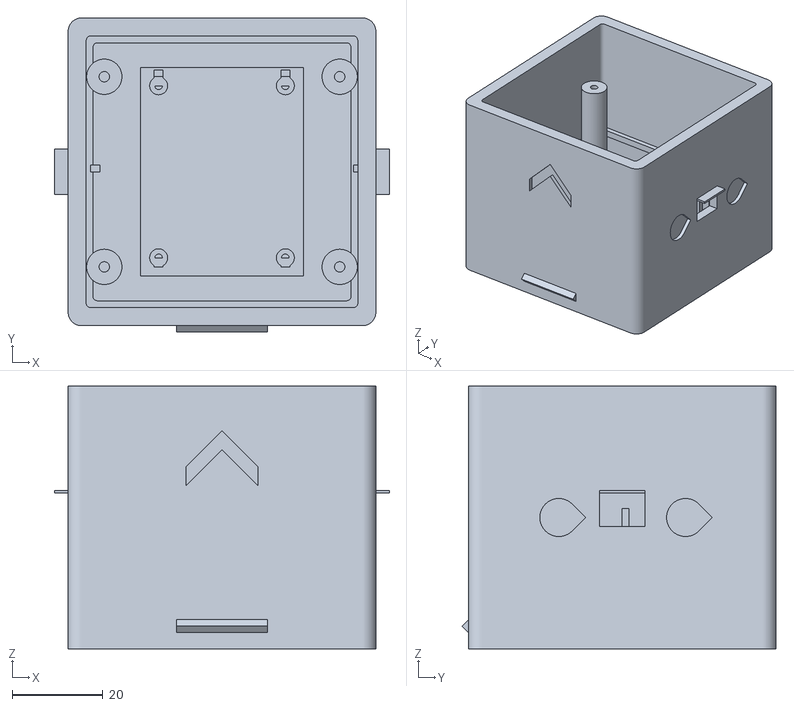
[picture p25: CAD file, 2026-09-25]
print_batch/Batch1_Shells/outer_box.stl
74.0 x 69.4 x 58.0

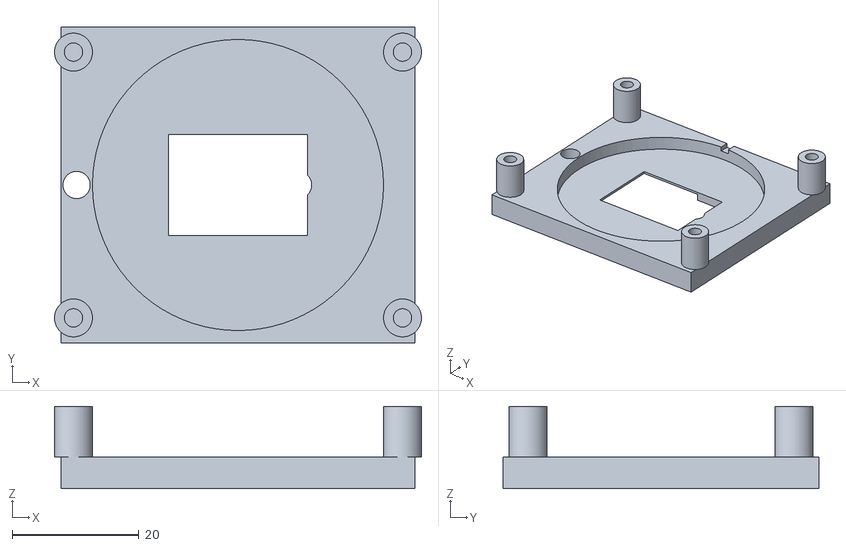
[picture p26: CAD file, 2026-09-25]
print_batch/Batch2_Plates/base_plate.stl
58.0 x 50.0 x 13.0

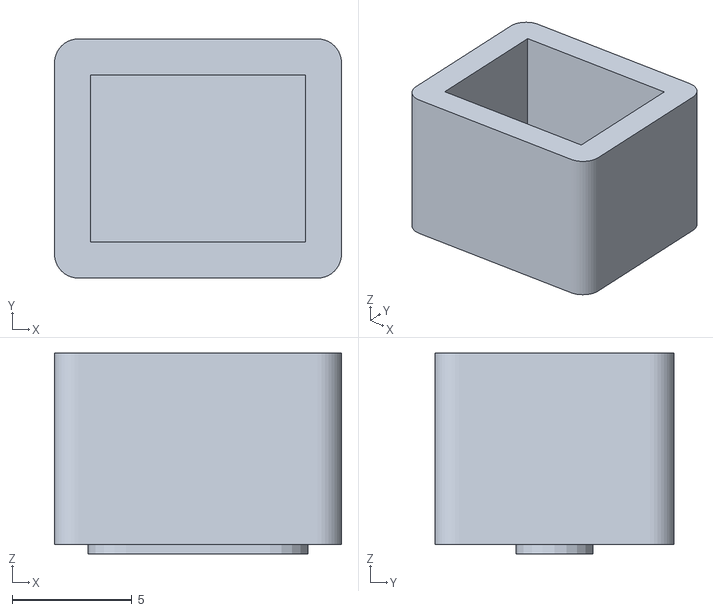
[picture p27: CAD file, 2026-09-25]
print_batch/Batch3_Small_Parts/pogo_end_cap.stl
12.0 x 10.0 x 8.40

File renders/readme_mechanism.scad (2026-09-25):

// =========================================================
// RENDER SCENE — the mechanism, for the README
//
// Not a printable part. This assembles the real geometry so the README can show
// a photograph of the mechanism instead of an ASCII sketch: the cam disc, the six
// linkages standing in their true positions, the comb that guides them, and the
// top plate above.
//
// One dot is RAISED and the other five are DOWN, which is the whole point of the
// picture: the raised linkage's foot sits on a high section of its track, and its
// dome stands proud of the reading surface.
//
// Render with PREVIEW, not --render. Transparency is an OpenCSG feature; CGAL
// discards alpha and the enclosure comes out solid.
//
//   openscad --camera=... -o ../docs/img/mechanism.png readme_mechanism.scad
//
// Everything is placed in LINKAGE-LOCAL Z: z=0 is the flat cam surface, which is
// the datum linkage_3d_v4() is built against. World z is not used here.
// =========================================================

include <../cad/scad/mech_layout.scad>
use <../cad/scad/linkage.scad>        // linkage_3d_v4(dot)
use <../cad/scad/braille_cam.scad>    // braille_cam()
use <../cad/scad/linkage_comb.scad>   // linkage_comb()
use <../cad/scad/top_plate.scad>      // top_plate()
use <../cad/scad/dot_insert.scad>     // dot_insert()

// Which dot is shown raised. 5 sits at phase 0 on the innermost track, so its
// arm runs straight along +X and reads clearly from the side.
raised_dot = 5;

show_comb      = true;
show_top_plate = true;
show_insert    = true;

// Export one component at a time, so Blender can give each its own material:
//   openscad -D only=\"cam\" -o cam.stl readme_mechanism.scad
// "all" renders the assembled scene, which is what the OpenSCAD preview uses.
only = "all";
function want(x) = (only == "all") || (only == x);

// braille_cam() puts the hub bottom at z=0, so the flat cam surface lands at
// hub_h + disk_base_thickness. Drop the disc by that much to put the flat at z=0.
cam_drop = 4 + 2;

$fn = 64;

// Same transform as export_linkage_assembly.scad. The -link_thickness/2 shift is
// load bearing: linkage_3d_v4() is extruded from local z=0, but its dome sits at
// local z=thickness/2, so without it every dot lands half a thickness off its hole.
module linkage_at(d, lift) {
    p = dot_pos(d);
    translate([p[0], p[1], lift])
        rotate([0, 0, asm_ang(d)])
            rotate([90, 0, 0])
                translate([0, 0, -link_thickness / 2])
                    linkage_3d_v4(d);
}

// --- the cam disc ---------------------------------------------------------
if (want("cam"))
    color([0.20, 0.22, 0.26])
        translate([0, 0, -cam_drop])
            braille_cam();

// --- the six linkages -----------------------------------------------------
// The raised one is warm and bright; the rest are cool grey and sit down.
for (d = [1:6])
    if ((want("linkages_down") && d != raised_dot) || (want("linkage_up") && d == raised_dot))
        color(d == raised_dot ? [0.95, 0.62, 0.25] : [0.72, 0.75, 0.80])
            linkage_at(d, d == raised_dot ? pin_lift : 0);

// --- the guide ------------------------------------------------------------
// Kept faint. It sits directly over the cam, and any more opacity than this
// hides the track profile underneath, which is the thing worth seeing.
if (show_comb && want("comb"))
    color([0.35, 0.55, 0.75, 0.16])
        linkage_comb();

// --- the reading surface --------------------------------------------------
// Ghosted, so the raised dome is visible through it rather than hidden by it.
if (show_top_plate && want("plate"))
    color([0.85, 0.87, 0.90, 0.13])
        translate([0, 0, plate_under_y])
            top_plate();

// The resin tile is OPAQUE and is the reading surface itself: insert_h is defined
// as the reading-surface height above the plate underside, so its top face IS the
// surface a finger touches. With it solid, a lowered dome is flush and invisible,
// and the raised dome clearly stands proud. That contrast is the whole picture.
//
// It sits AT plate_under_y. An earlier version added (4 - 3.2) and lifted the tile
// 0.8mm, which put the reading surface level with the plate rim instead of inside
// the finger recess, and hid the lift.
if (show_insert && want("insert"))
    color([0.88, 0.89, 0.92])
        translate([0, 0, plate_under_y])
            dot_insert();

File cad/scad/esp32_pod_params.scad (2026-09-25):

// =========================================================
// ESP32 BRAIN POD — Shared Parameters & Base Modules
// Revision 3.0 — Matching Brick + Horizontal Socket Mount
// Updated 2026-05-31
//
// Pod now shares the cell's docking face (68 wide × 58 tall)
// so the chain looks like a uniform row of bricks.
//
// Owned ESP32 USB-C DevKit (30-pin, ~51.5×28mm family) mounts HORIZONTALLY
// on two 1×15 female header strips — plug-and-play, no soldering.
//
// include <esp32_pod_params.scad>
// =========================================================

include <stack_options.scad>
include <dock_interface.scad>

// --- POD SHELL DIMENSIONS ---
// v7.5: 64 -> 68. The 51.5mm board offset +4mm in X spanned x = -21.75..+29.75
// inside a cavity that ended at +28 — a 1.75mm interference, so the DevKit
// physically would not go in. 68 makes the internal cavity 60 (+/-30) and, as a
// bonus, makes the pod a 68x68x58 cube exactly matching a cell, so the docked
// chain really is a uniform row of bricks. The +X dock face is unchanged.
pod_length       = 68;     // X — depth (USB end to dock end)
pod_width        = 68;     // Y — matches cell shell_width for uniform chain look
// v8.5: 58 -> 44, following the cell. The pod was never full - floor 3, wire tail
// 5, header 8.5, board 1.6, tallest component ~4, clearance 3 and a 4mm lid come to
// about 29mm. At 44 there is still 15mm spare.
pod_height       = 46.5 + stack_repair_raise; // Z — matches cell shell_height
pod_wall         = 4;      // Wall thickness
pod_floor        = 3;      // Floor thickness
pod_fillet       = 3.0;    // Outer corner radius — matches cell (was 2.0)

lid_h            = pod_wall;   // 4mm lid

// Internal cavity
pod_int_length   = pod_length - 2 * pod_wall;  // 56mm
pod_int_width    = pod_width  - 2 * pod_wall;  // 60mm

// --- ESP32 DEVKIT V1 MOUNTING (horizontal on female header sockets) ---
// Board: ~51.5 × 28mm, 15 pins/side, measured pin-row pitch 25.6mm (M21)
// Two 1×15 female header strips sit in printed channels on the floor.
// DevKit's male pins plug straight down — zero soldering, fully removable.
devkit_length    = 51.5;   // LIKELY (M19) — matching USB-C CH340C 30-pin listings
devkit_width     = 28.0;   // LIKELY (M20) — matching board family; listings reach 28.5

// M18: 15 pins per side / 30 total. M21: 25.6mm centre-to-centre on the owned
// USB-C board. This is close to the nominal 1.0" (25.4mm) family, but the owned
// reading controls the printed socket-channel locations.
hdr_row_pitch    = 25.6;   // MEASURED (M21) — pin-row centre-to-centre
hdr_strip_w      = 2.7;    // Female header strip body width
hdr_strip_h      = 8.5;    // Female header strip body height (board sits at floor+8.5)
hdr_strip_len    = 40.0;   // 15-pin strip length (~15×2.54=38.1, round up)
hdr_tail_space   = 5.0;    // prewired lower-tail/solder/wire service space
hdr_body_bottom_z = pod_floor + hdr_tail_space; // raised socket-body seat at z=8
hdr_cradle_w     = 3.2;    // 2.7mm body + 0.5mm lateral clearance
hdr_cradle_len   = 40.4;   // 40.0mm body + 0.4mm end clearance

// Board position: centred in Y, biased toward the -X/USB wall.
// v7.5: +4 -> -2. Pushing the board TOWARD the USB wall shortens how far the plug
// has to reach inboard to seat (was 6.25mm, now 2.25mm), and still leaves 6.25mm
// at the +X end for the pogo/dock wiring.
//   board spans x = -2 +/- 25.75 = -27.75 .. +23.75, inside a +/-30 cavity.
devkit_x_offset  = -2;

// --- OWNED INLINE POWER PIGTAIL (through the LID) ---
// The photographed connector is a female inline lead, not a threaded panel jack.
// Keep its body outside the pod and pass only the red/black cable pair through this
// rounded slot. Secure the cable to the existing internal tie post before soldering;
// plug-in force then loads the tie, not the ESP32 or lid.
power_cable_slot_w = 6.0;  // generous for the pictured two-wire pair
power_cable_slot_h = 4.0;
power_cable_x      = -20;
power_cable_y      = 24;   // 8mm nominal clearance beyond board/slot edge
// --- USB CUTOUT (-X end wall) ---
// v7.5: the old usb_z had an arithmetic bug — it ignored hdr_channel_depth. The
// header strips are RECESSED 1mm into the floor, so the board underside sits at
// pod_floor + hdr_strip_h - hdr_channel_depth = 10.5, not 11.5. The cutout was
// therefore ~2mm too high and only ~0.5mm of it overlapped the actual socket;
// the port was effectively behind solid wall.
// Service opening is intentionally larger than the USB-C shell so common cable
// overmoulds can reach the socket 2.25mm inboard. Keep the existing 9mm height:
// reducing it to 7mm would regress the cable-body clearance fixed in v7.5.
usb_w            = 14;     // Fixed service envelope; measure only unusually large cables
usb_h            = 12;     // conservative service envelope, z=14..26
board_under_z    = hdr_body_bottom_z + hdr_strip_h; // nominal 16.5
usb_z            = 14;

// --- POGO INTERFACE (+X dock wall) ---
// Matches cell ±X pogo window exactly
pogo_pad_w       = dock_receiver_w;
pogo_pad_h       = dock_receiver_h;
pogo_z_from_bot  = dock_center_z;

// --- MAGNET POCKETS (+X dock wall) ---
// v6.1: real magnets are 8mm dia × 1mm thick (was 3×2). 2 per face at y=±14,
// matching the cell exactly so docked magnets align. Teardrop tops (FDM).
// Cell -X face = N/S; pod +X face = S/N → attract, repel reversed
mag_dia          = dock_mag_dia;  // v8.6: shared, see dock_interface.scad
mag_depth        = 1.2;   // 1mm magnet + glue gap (4mm wall keeps 2.8mm)
// v8.9: follows the cell - the wider pogo window pushed these outboard.
mag_y_positions  = [-dock_mag_y, dock_mag_y];
// Dock features stay at the same absolute height when Option A adds headroom.
// v8.6: WAS 29 AND WRONG. The comment said "matches cell" and stopped being true
// the moment the cell dropped 14mm; the two magnet rings were 15.5mm apart.
mag_z            = dock_mag_z;    // 13.5, derived - do not hand-copy this

// --- WIFI ANTENNA GRILLE (+X end, near dock) ---
antenna_wall     = 1.5;
antenna_slot_w   = 3;      // v6.1: 2→3mm (2mm slots fused on the fit-test printer)
antenna_slot_h   = 8;
antenna_slot_count = 3;

// --- WIRE TIE POST ---
tie_post_dia     = 4;
tie_post_h       = 10;
tie_slot_w       = 1.6;   // normal mini zip-tie thickness + print clearance
tie_slot_h       = 3.2;   // normal mini zip-tie width + print clearance
power_tie_x      = power_cable_x;
power_tie_y      = pod_int_width/2 - 4;

// --- NAVIGATION BUTTONS (front face, -Y wall) ---
// 3× PS-style flanged caps: Previous (<), Select (O), Next (>)
// 6×6×5mm tactile switches held in printed snap pockets behind wall
nav_shaft_dia    = 3.8;    // resin stem; 0.4mm diametral clearance in the Ø4.2 PETG hole
nav_hole_dia     = 4.2;    // 0.2mm sliding clearance
nav_flange_dia   = 8.0;
nav_flange_h     = 1.5;
nav_cap_body_dia = 7.5;
nav_cap_body_h   = 3.5;
nav_shaft_len    = 4.5;    // measured from flange INNER face: 4mm wall + 0.5mm to switch plunger
nav_z            = 58 * 0.42;  // ~24.4mm; keep switch/USB wiring geometry stable
nav_x_positions  = [-20, 0, 20];

// --- TACTILE SWITCH POCKET (behind each nav hole, inside front wall) ---
sw_body          = 6.4;    // 6mm switch + 0.4mm clearance
sw_depth         = 5.5;    // switch is 5mm + 0.5mm clearance behind
sw_snap_nib      = 0.8;    // retention nib overhang (v6.1: 0.4→0.8, was sub-layer thin)

// --- LID SCREW BOSSES ---
// v6.1b: 25→27.5. At x=25 the Ø5 bosses FLOATED 0.5mm off the inner wall (x=28) —
// disconnected bodies in the STL, printed as loose/spaghetti towers. At 27.5 the
// boss embeds 2mm into the wall. Lid holes follow automatically (same param).
// v7.5: HARD-CODED 27.5 IS NOW A FORMULA — and that is not cosmetic.
// 27.5 was correct only while pod_int_length was 56 (inner wall at x=28, so a Ø5
// boss at 27.5 spanned 25..30 and embedded 2mm into the wall). Lengthening the pod
// moved the inner wall to x=30, which would have left the boss exactly TOUCHING it
// — the precise floating-boss bug this comment block was written about the first
// time. Tie it to the wall so it can never drift again.
lid_screw_x      = pod_int_length/2 - 0.5;   // 29.5 — boss still embeds 2mm
lid_screw_d      = 2.9;    // v8.3: M2 -> M2.5 clearance in lid (was 2.8 for M2)
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

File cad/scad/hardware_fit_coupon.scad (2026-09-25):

// Braillix hardware fit coupon — print before any large enclosure part.
// PETG, 0.16mm, 5 walls, 40% infill, no supports.
// Tests printer/material compensation for the unpurchased heat inserts and
// measured motor shaft, Hall body and 8x1mm docking magnets.

$fn = 48;
plate_x = 110;
plate_y = 34;
plate_z = 6;

module rounded_plate() {
    hull()
        for (sx=[-1,1], sy=[-1,1])
            translate([sx*(plate_x/2-3), sy*(plate_y/2-3), 0])
                cylinder(r=3, h=plate_z);
}

module double_d_hole(d, flats, h) {
    intersection() {
        cylinder(d=d, h=h);
        translate([-d, -flats/2, 0]) cube([2*d, flats, h]);
    }
}

module shallow_label(label, x, y) {
    translate([x, y, plate_z-0.35])
        linear_extrude(0.5)
            text(label, size=3.2, halign="center", valign="center");
}

difference() {
    rounded_plate();

    // Heat-set insert bores: 1mm floor remains. Pick the best melt-in fit.
    for (i=[0:3]) {
        d = [3.1, 3.3, 3.5, 3.7][i];
        x = -45 + i*15;
        translate([x, 8, 1]) cylinder(d=d, h=plate_z);
        shallow_label(str(d), x, 14);
    }

    // 28BYJ-48 double-D shaft: Ø5.2, three across-flat clearances.
    for (i=[0:2]) {
        flats = [3.1, 3.2, 3.3][i];
        x = -45 + i*15;
        translate([x, -10, -0.5]) double_d_hole(5.2, flats, plate_z+1);
        shallow_label(str(flats), x, -3.5);
    }

    // 8x1mm docking magnet glue pockets, 1.2mm deep.
    for (i=[0:2]) {
        d = [8.2, 8.4, 8.6][i];
        x = 12 + i*17;
        translate([x, 8, plate_z-1.2]) cylinder(d=d, h=2);
        shallow_label(str(d), x, 14);
    }

    // Bare Hall-body pockets: measured 1.6mm thick plus 0.1/0.2/0.3mm Z margin.
    for (i=[0:2]) {
        depth = [1.7, 1.8, 1.9][i];
        x = 12 + i*17;
        translate([x-2.25, -11.75, plate_z-depth]) cube([4.5, 3.5, depth+0.5]);
        shallow_label(str(depth), x, -4.5);
    }
}

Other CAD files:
print_batch/Batch4_Resin/linkage.stl
renders/Untitled.stl
cad/models/kicad/DIP-16_W7.62mm.step
cad/stl/hardware_fit_coupon.stl
cad/scad/motor_cam_socket_coupon.scad
_archive/Untitled.stl
_archive/test_box.scad
_archive/test_buttons_only.scad
_archive/test_buttons_only.stl
_archive/test_full_no_guards.scad
_archive/test_full_no_guards.stl
_archive/test_original.scad
_archive/test_original.stl
_archive/top_plat.stl
cad/models/kicad/BarrelJack_CUI_PJ-063AH_Horizontal.step
cad/models/kicad/PinSocket_1x15_P2.54mm_Vertical.step
cad/scad/base_interface_coupon.scad
cad/scad/base_plate.scad
cad/scad/braille_cam.scad
cad/scad/braille_cam2.scad
cad/scad/braille_cap.scad
cad/scad/cam_linkage_test_fixture.scad
cad/scad/cam_linkage_test_resin_set.scad
cad/scad/dock_interface.scad
cad/scad/dot_insert.scad
cad/scad/electronics_spec.scad
cad/scad/esp32_pod_assembly.scad
cad/scad/esp32_pod_lid.scad
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

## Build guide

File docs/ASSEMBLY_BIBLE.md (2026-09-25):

# Braillix - Assembly Bible & Wiring Guide

> [!IMPORTANT]
> **CURRENT RELEASE GATE - 2026-08-19:** Do not assemble the full printed mechanism from this guide
> yet. The production cam has an invalid 3.5mm socket for the measured 7.5mm shaft, and the complete
> stack remains on HOLD. Print only the files in `printing/gcode_kobra_neo_checked` and follow
> `PRINT_RELEASE_2026-08-19.md` plus `MECHANISM_BENCH_TEST.md`. Resume final assembly only after a
> later release explicitly removes this gate.

Follow this guide sequentially to build your first single-cell prototype.

---

## SECTION 1: CRITICAL SAFETY CHECKS (DO THIS FIRST)

> [!CAUTION]
> **BARREL JACK POLARITY CHECK**
> The photographed inline female pigtail has red/black wires, but colour is not proof. If you wire 5V backwards, the ULN2003 chip can burn out.
> 1. Plug the 5V adapter into the wall.
> 2. Plug the adapter's round male plug into the black inline female pigtail. Keep both stripped wires disconnected from the circuit.
> 3. Turn on your Multimeter and set it to **DC Voltage (V DC)**.
> 4. Touch the RED probe to the exposed red wire and the BLACK probe to the exposed black wire.
> 5. If the screen reads approximately **`+5.0V`**, red is **POSITIVE (+)** and black is **GND (-)**.
> 6. If it reads approximately **`-5.0V`**, the pigtail colours are reversed. Do not connect it until the wires are relabelled.
> 7. Disconnect wall power before attaching either wire to the breadboard.

---

## SECTION 2: WIRING DIAGRAM

We are wiring the **ESP32**, **ULN2003**, and **Hall Sensor** together.

```text
[5V/3A Adapter] 
      |
      +---> (+) ---> [BREADBOARD 5V RAIL] ---> ULN2003 (+) power pin
      |
      +---> (-) ---> [BREADBOARD GND RAIL] ---> ULN2003 (-) power pin

[ESP32 (Powered by USB)]
   GND  -------------------------> [BREADBOARD GND RAIL] (Crucial: Common Ground!)
   3V3  -------------------------> Hall Sensor VCC
   GND  -------------------------> Hall Sensor GND
   D34  <------------------------- Hall Sensor AO (Analog Out)
   D18  -------------------------> ULN2003 IN1
   D19  -------------------------> ULN2003 IN2
   D21  -------------------------> ULN2003 IN3
   D22  -------------------------> ULN2003 IN4

[ULN2003 Output]
   White JST Socket -------------> 28BYJ-48 Stepper Motor
```

### Kill-Shots to Avoid:
1. **Never** connect the 5V rail to the Hall Sensor VCC. ESP32 pins are not 5V tolerant. Use `3V3`.
2. **Never** connect the 5V adapter rail to the ESP32 `VIN` pin while the USB cable is plugged into your laptop. Power the motor from the adapter, and the ESP32 from USB. Only link their grounds.

---

## SECTION 3: CURRENT PRE-ASSEMBLY VALIDATION SEQUENCE

### Phase A: PETG fit evidence

1. Print `motor_cam_socket_coupon.gcode`; test the unpowered shaft from 3.1 to 3.3mm and record the
   smallest removable fit. Never hammer, heat, power, glue, or cut the shaft during this test.
2. Print `base_interface_coupon.gcode`. Inspect the Ø29 motor-seat roof for sag, test the actual M4
   screw in the 3.3/3.4/3.5mm through pilots, and test the M2.5 bolt in the 2.9/3.0/3.1mm Ø6x12
   standoffs. Do not force a bore that whitens or splits.
3. Print the remaining required coupons in `PRINT_RELEASE_2026-08-19.md` and record every selected
   fit before changing a production dimension.

### Phase B: electronics bring-up outside the enclosure

1. Keep the ESP32 on USB and the motor on the 5V adapter; connect grounds.
2. Power the bare Hall sensor/module from ESP32 `3V3`, not 5V, and use `AO` for the initial test.
3. Verify motor direction, homing response, and the already measured red-positive pigtail polarity
   on the breadboard. Do not install electronics in an unreleased enclosure.

### Phase C: cam/linkage/spring bench evidence

1. Print `cam_linkage_test_fixture.gcode` in PETG.
2. Obtain the four-part `cad/stl/cam_linkage_test_resin_set.stl` in resin plus the actual 2mm OD
   spring. Do not use PETG linkages or a pen spring.
3. Follow `MECHANISM_BENCH_TEST.md` for dot-5 and dot-6 dry travel, 50-cycle return, dwell, damage,
   height, and torque tests. The fixture is evidence equipment, not the final enclosure.

### Phase D: final assembly - intentionally blocked

Do not press the current production cam onto the motor, trim the shaft, glue the Hall sensor, glue
magnets, install heat-set inserts, or glue the resin dot insert yet. Those actions either hide a
failed fit or are difficult to reverse. A later validated release must provide the corrected cam,
base/Hall stack, enclosure height, selected coupon dimensions, and final assembly sequence.
## SECTION 4: BEGINNER SOLDERING MISTAKES
If you are doing the flat-soldering for the ULN2003:
- **Cold Joint:** Looks like a dull, grey blob that doesn't stick to the pad. *Fix: Apply a tiny bit of flux, heat the pin and wire simultaneously for 2 seconds, and reapply a dab of solder.*
- **Bridging:** Solder spills over and connects two pins (e.g., IN1 and IN2). This will break the motor steps. *Fix: Heat the bridge and swipe your iron away quickly, or use desoldering wick to soak up the excess.*
- **Melted Insulation:** Holding the iron on the wire too long melts the plastic jacket. *Fix: Tin the wire and pin separately first (apply solder to them individually), then just touch them together with the iron for 1 second to fuse them.*

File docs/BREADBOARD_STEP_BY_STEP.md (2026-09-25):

# Braillix — Breadboard Wiring: EVERY SINGLE WIRE

**No soldering. No guessing. Follow this exactly.**

---

## Your parts (confirmed from photos)

```
A. ESP32 DevKit (30-pin, USB-C, CH340C)
B. ULN2003 driver module (green PCB, white JST socket, 4 LEDs)
C. 28BYJ-48 stepper motor (silver, 5-wire white JST plug)
D. Hall sensor module (blue, "MH-Sensor-Series", 4 pins: AO DO GND VCC)
E. Barrel jack pigtail (black female socket, red wire = +5V, black wire = GND)
F. 5V/3A adapter (yellow barrel plug)
G. 4x 4.7k resistors (NOT NEEDED for this test — save for later)
H. Breadboard + dupont jumper wires
```

---

## STEP 0: Prep (power OFF, nothing plugged in yet)

```
[ ] Adapter NOT plugged into wall
[ ] ESP32 NOT plugged into laptop USB
[ ] Have 8+ male-to-male dupont jumper wires ready
[ ] Have 2+ male-to-female dupont jumpers (for hall module)
[ ] Breadboard on desk, nothing in it
```

---

## STEP 1: Place ESP32 on breadboard

```
Breadboard layout (top view):

     LEFT RAIL          BREADBOARD HOLES           RIGHT RAIL
     (+) (-)     1  2  3  4  5 | 6  7  8  9 10    (+) (-)
                 ←  ESP32 straddles the gap  →

ESP32 is WIDE. Push it so:
  - Left row of pins go into column 1 (or 2)
  - Right row of pins go into column 9 (or 10)
  - You should have at least 1 column free on each side for jumpers

USB-C port faces toward you (bottom of breadboard).
```

**Pin layout on YOUR board (read from the silkscreen):**

```
LEFT SIDE (USB at bottom):          RIGHT SIDE (USB at bottom):
  VIN  ←── do NOT connect             3V3  ←── hall VCC goes here
  GND  ←── CONNECT TO GND RAIL        GND  ←── also GND
  D13                                 D15
  D12                                 D2
  D14                                 D4
  D27                                 D16
  D26                                 D17
  D25                                 D5
  D33                                 D18  ←── ULN2003 IN1
  D32                                 D19  ←── ULN2003 IN2
  D35                                 D21  ←── ULN2003 IN3
  D34  ←── hall AO goes here          RX0
  VN                                  TX0
  VP                                  D22  ←── ULN2003 IN4
  EN                                  D23
```

---

## STEP 2: Power rails

```
                    BREADBOARD
          (+) RED rail ─────────────── (+)
          (-) BLUE rail ────────────── (-)

Wire 1: ESP32 "GND" pin (left side) → jumper → (-) BLUE rail
         (THIS IS THE MOST IMPORTANT WIRE — common ground)

Wire 2: Strip barrel jack RED wire → poke into (+) RED rail
Wire 3: Strip barrel jack BLACK wire → poke into (-) BLUE rail
         (same rail as ESP32 GND — they SHARE ground)
```

**DO NOT connect the (+) RED rail to ESP32 VIN.** Ever. While USB is plugged in.

---

## STEP 3: ULN2003 driver module

The green module has these pins along one edge:

```
ULN2003 module pin header:
  IN1  IN2  IN3  IN4  (-)  (+)

And on the other side: white JST socket for motor
```

```
Wire 4: ULN2003 "IN1" → jumper → ESP32 D18  (GPIO 18)
Wire 5: ULN2003 "IN2" → jumper → ESP32 D19  (GPIO 19)
Wire 6: ULN2003 "IN3" → jumper → ESP32 D21  (GPIO 21)
Wire 7: ULN2003 "IN4" → jumper → ESP32 D22  (GPIO 22)
Wire 8: ULN2003 "(+)" → jumper → breadboard (+) RED rail  (5V from adapter)
Wire 9: ULN2003 "(-)" → jumper → breadboard (-) BLUE rail (GND)
```

**Motor:** Just push the 28BYJ-48's white JST plug into the ULN2003's white socket.
It only fits one way. No wires to connect — it's a plug.

---

## STEP 4: Hall sensor module

Your module is **MH-Sensor-Series (KY-024 type)**. Pins (reading from the silkscreen):

```
  AO   DO   GND   VCC
  │    │     │     │
  ↓    ↓     ↓     ↓
```

**Use male-to-female dupont jumpers** (female end plugs onto the module pins):

```
Wire 10: Hall "VCC" → ESP32 "3V3" pin (right side of board)
Wire 11: Hall "GND" → breadboard (-) BLUE rail
Wire 12: Hall "AO"  → ESP32 D34  (GPIO 34, left side of board)
```

**DO NOT connect Hall VCC to 5V.** It must be 3V3. At 3.3V the analog output (AO) stays
within 0–3.3V which is safe for ESP32. At 5V, AO could hit 5V and fry GPIO34.

**Hall "DO" pin:** leave unconnected (we use AO for analog reading — more useful for homing).

---

## STEP 5: Summary — all 12 wires

| Wire # | FROM | TO | Color suggestion |
|---|---|---|---|
| 1 | ESP32 GND (left) | (-) blue rail | BLACK |
| 2 | Barrel jack RED wire | (+) red rail | RED (it already is) |
| 3 | Barrel jack BLACK wire | (-) blue rail | BLACK (it already is) |
| 4 | ULN2003 IN1 | ESP32 D18 | any color |
| 5 | ULN2003 IN2 | ESP32 D19 | any color |
| 6 | ULN2003 IN3 | ESP32 D21 | any color |
| 7 | ULN2003 IN4 | ESP32 D22 | any color |
| 8 | ULN2003 (+) | (+) red rail | RED |
| 9 | ULN2003 (-) | (-) blue rail | BLACK |
| 10 | Hall VCC | ESP32 3V3 | RED or ORANGE |
| 11 | Hall GND | (-) blue rail | BLACK |
| 12 | Hall AO | ESP32 D34 | GREEN or YELLOW |

**Motor: JST plug into ULN2003 socket. No wires.**

---

## STEP 6: Pre-power checklist

```
[ ] ESP32 GND connected to (-) rail? (Wire 1)
[ ] Barrel jack black wire in (-) rail? (Wire 3 — same rail as wire 1)
[ ] Barrel jack red wire in (+) rail? (Wire 2)
[ ] (+) rail is NOT connected to ESP32 VIN? (must be empty!)
[ ] ULN2003 (+) goes to (+) rail? (Wire 8)
[ ] ULN2003 (-) goes to (-) rail? (Wire 9)
[ ] Hall VCC goes to ESP32 3V3, NOT to (+) rail? (Wire 10)
[ ] Hall AO goes to D34? (Wire 12)
[ ] Motor JST plugged into ULN2003?
[ ] No loose wires touching each other?
```

---

## STEP 7: Power on + upload code

**Order matters:**
1. Plug ESP32 into laptop via USB-C cable
2. Open Arduino IDE
3. Select board: **ESP32 Dev Module**
4. Select port: the COM port that appeared (e.g. COM3, COM5)
5. Open `firmware/breadboard_test/breadboard_test.ino`
6. Click Upload (→ arrow)
7. Wait for "Done uploading"
8. Open Serial Monitor (magnifying glass icon), set baud to **115200**
9. Press the **EN** button on ESP32 (tiny button near USB) to restart
10. You should see: `=== Braillix Breadboard Test ===`
11. NOW plug the 5V adapter into the wall (motor gets power)

---

## STEP 8: What to expect

```
[TEST 1] Hall sensor baseline (no magnet):
  hall = 1850    ← some mid-range value (varies by module)
  hall = 1847
  ...

[TEST 2] Spinning CW (512 steps = quarter turn)...
  → Motor shaft should visibly turn ~90 degrees
  → ULN2003 LEDs should flicker in sequence
  Done.

[TEST 3] Spinning CCW (512 steps = quarter turn)...
  → Motor should turn back to where it started
  Done.

[TEST 4] Full CW revolution, printing hall every 64 steps:
  step=0    hall=1850
  step=64   hall=1852
  ...
  → Wave a magnet over the hall sensor while this runs
  → You should see: hall=1850 suddenly jump to hall=3200+ (or drop to 200)
  → That change = the sensor detected the magnet = homing will work!

Entering continuous hall monitor...
  hall=1850
  hall=1849
  (wave magnet)
  hall=3400   ← MAGNET DETECTED
  hall=3380
  (remove magnet)
  hall=1855   ← back to baseline
```

---

## Troubleshooting

| Problem | Fix |
|---|---|
| Nothing happens when uploaded | Press EN button. Check Serial Monitor is 115200. |
| "Failed to connect to ESP32" | Hold BOOT button while uploading, release after "Connecting..." |
| Motor buzzes but doesn't spin | Swap pin order in code: try `IN1=18, IN3=19, IN2=21, IN4=22` (swap middle pair). Or check ULN2003 (+) has 5V. |
| Motor doesn't move at all | Check ULN2003 (+) and (-) are connected to adapter rails. Is adapter plugged in? |
| ULN2003 LEDs don't light | Adapter not on, or (+)/(-) reversed. Check polarity! |
| Hall reads 0 always | VCC not connected. Check wire 10 goes to 3V3. |
| Hall reads 4095 always | GND not connected. Check wire 11. |
| Hall doesn't change with magnet | Wrong side of sensor facing magnet. Flip it. Also try getting VERY close (<5mm). |
| ESP32 resets when motor moves | The adapter 5V rail is drooping. Make sure ESP32 is on USB ONLY, not sharing VIN with motor. |

---

## What's next after this works?
1. Keep the motor, cam, magnet, and Hall sensor loose on the bench.
2. Run the fit coupons and mechanism bench test in `PRINT_RELEASE_2026-08-19.md` and
   `MECHANISM_BENCH_TEST.md`; the current production cam/socket and Hall pocket are on HOLD.
3. Write homing firmware: spin until Hall crosses the threshold → that is position 0.
4. Index to any of the 64 cam positions on command.

Do **not** trim the shaft, press or glue the current cam, or glue the Hall sensor into the
production base. Final mechanical assembly waits for the measured stack repair and coupon results.

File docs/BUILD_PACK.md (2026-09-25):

# Braillix — Build Pack

> **CURRENT RELEASE GATE - 2026-08-19:** This pack predates the full print-readiness audit. Do not
> permanently assemble or print production cam/base/top/enclosure/pod parts from its older status
> claims. Current authority is `PRINT_RELEASE_2026-08-19.md`, `PRINT_DAY_MONDAY.md`, and
> `MECHANISM_BENCH_TEST.md`. Only the checked G-code folder is released; the full product is NO-GO.

**Written 2026-08-15. For the 24 August evaluation.**
Scope: **electronics, assembly and sourcing.** Mechanical/CAD issues are *flagged* here and
fixed in the CAD fork, never here.

This is the single document to work from at the bench. It answers, in order:
what to present on 24 August, what can be permanently assembled now, what goes in which box,
how every wire connects, why each part exists, and exactly what is still to be ordered.

---

# PART 0 — The 24 August plan

## The upper linkages are not on the critical path

The six linkages are the hardest parts in the project and they are giving trouble. **Do not
let them decide whether you have a demo.** Nothing in the electronics or the actuation chain
depends on them existing.

Split the project the way an evaluator will accept:

| Layer | State on 24 Aug | How it is shown |
|---|---|---|
| Encoding — 64 states, 6 dots | ✅ Solved, provable | Simulator + the 64-state table |
| Actuation — motor, cam, homing | 🔴 **HOLD** | Current cam socket cannot install; use the coupon/bench fixture only |
| Control — ESP32, WiFi dashboard | ✅ **Buildable now** | **Phone browser, live** |
| Transmission — linkages to dots | 🟠 In progress | Simulator, plus one linkage held by hand |

**Three of four layers are real hardware.** That is a legitimate mid-project result, and it is
far stronger than a fully-assembled unit that does not move.

## What the demo actually looks like

```
   [ Phone ] --wifi--> [ ESP32 ] --> [ ULN2003 ] --> [ 28BYJ-48 ] --> [ CAM DISC ]
   type "h"            picks state    switches         turns 5.625deg     visibly
                       17 of 64       the coils        per state          rotates
                                          ^
                                     [ HALL SENSOR ] finds home on power-up

   Projected beside it: the 3D simulator, showing the SAME state number
   driving the six dots up and down.
```

**Say this out loud to the panel:** the cam is an absolute 6-bit rotary encoder; the hardware
proves it reaches every one of 64 positions repeatably; the simulator proves each position
lifts the correct dots. **The linkage is the assembly step in progress.** That framing is
honest and it is the actual engineering status.

⚠️ **Do not promise raised dots on 24 August.** If the linkages come good before then, it is a
bonus you add. Building the demo around them is how you end up with nothing.

---

# PART 1 — What is safe to make PERMANENT right now

You have the iron. The question is what you can commit to without regretting it.

| # | Job | Permanent? | Verdict |
|---|---|---|---|
| 1 | Header pins onto the DC jack's bare wires | Yes | ✅ **Do it.** The jack's job never changes. |
| 2 | Wires soldered **flat** to ULN2003 `IN1`–`IN4` + power | Yes | ✅ **Do it.** Required by the 14mm pocket, and the ULN2003 end of those wires is fixed no matter which GPIO the other end lands on. |
| 3 | The power spine (one 5V source, three branches) | Yes | ✅ **Do it.** Wire it with a screw terminal block if you would rather not splice. |
| 4 | Heat-set brass inserts into the printed parts | Yes | ✅ **Do it** — see Part 7. The iron you just bought is the tool for this. |
| 5 | Desoldering the hall TO-92 off its blue module | Yes | 🟠 **Wait.** See the caution below. |
| 6 | Super glue on the `dot_insert` tile | Yes | 🟠 **Wait** until the top plate and the dot alignment are confirmed. |
| 7 | Soldering **anything** directly to ESP32 GPIO pins | Yes | 🔴 **Never.** See below. |

### 🔴 Rule: nothing is soldered to an ESP32 GPIO

**The pin map is not frozen and will change twice more:**

1. The GPIO21/22 conflict fix — `IN3` moves to **23**, `IN4` to **27** (`ELECTRONICS_PLAN.md`
   Part 3).
2. The expander migration when a third cell appears (Part 5 of the same doc).

Every ESP32 connection stays **Dupont jumper into the header**. Solder is for the far end of
the wire, never the board end. This costs nothing and keeps the board reusable.

### 🟠 Caution before desoldering the hall sensor

The blue MH module is what makes the sensor usable today. Taking the sensor off it is
**irreversible and only needed for final assembly in the pod** — not for the demo, where the
module sits on the breadboard.

⚠️ **Read the part number on the black 3-legged sensor first.**

| Marking | Type | If you desolder it |
|---|---|---|
| `49E` / `SS49` | **Analog** | Fine — outputs a voltage directly, works on `AO` with no extra parts |
| `3144` / `A3144` | **Digital, open-collector** | ⚠️ Needs a **10kΩ pull-up** to 3V3 that currently lives on the module. Without it the output reads nothing. |

**Do not desolder before 24 August.** There is no benefit and a real chance of losing your
only sensor.

---

# PART 2 — Which box holds what

```
+============================+     +===============================+
|        BRAIN POD           |     |        MUSCLE CELL            |
|        (one, ever)         |     |        (one per character)    |
+============================+     +===============================+
| ESP32 DevKit    51x28mm    |     | 28BYJ-48 motor      19mm tall |
| 3 nav buttons              |     | Cam disc                      |
| DC power jack              |     | ULN2003 board    [!] 14mm max |
|                            |     | Hall sensor (bare TO-92)      |
| (3+ cells only:            |     |                               |
|  2x 4.7k pull-ups)         |     | (3+ cells only: MCP23017)     |
+============================+     +===============================+
             |                                    ^
             +----- 5V, GND, 4 control, 1 sense --+
                    (fixed 4 wires once expanders arrive)
```

## Vertical stack inside a cell — where the millimetres go

```
  z=58  +--------------------------+  top plate top surface, braille dots
  z=54  +--------------------------+  top plate underside
          |    8mm standoffs
  z=45    ----------------------      cam flat surface  (+0.8 at a bump)
  z=43  +--------------------------+  cam disc, 2mm floor
  z=41  +--------------------------+  base plate top / motor face
          |   19mm  28BYJ-48 body
  z=22  +--------------------------+
  z=20  +--------------------------+  mid plate, 2mm
          |   [!] 14mm ELECTRONICS POCKET  <-- the only tight space
  z=4   +--------------------------+
  z=0   +--------------------------+  box floor, 4mm
```

## Space, honestly

| Location | Space | Occupant | Margin |
|---|---|---|---|
| Electronics pocket | **36 x 46 x 14mm** | ULN2003, wires soldered flat ~12mm | 🔴 **~2mm. Zero slack.** |
| Pod interior | ~38mm headroom | ESP32 + jack + buttons | ✅ Wildly oversized |
| Cam-to-top-plate gap | 8mm standoffs | linkages, 12.2mm total height | 🟠 Set by the CAD fork |

🔴 **The 14mm pocket is why soldering exists in this project at all.** A ULN2003 with Dupont
jumpers plugged in vertically stands ~20mm and will not close the box. Cut the connectors off
and lay the wires flat and it drops to ~12mm.

⚠️ **The pocket lost 2mm** (16 → 14) in the 2026-08-01 CAD fix that corrected the motor stack.
It still clears, but check the fit with real soldered wires before closing the box.

---

# PART 3 — Every connection, colour coded

## 3.1 Power — do this first, and get it right

| From | Wire | To | Note |
|---|---|---|---|
| 5V adapter barrel | — | DC pigtail jack | |
| Jack `RED` (+5V) | `RED` | Breadboard **+ rail** | ✅ Polarity measured correct 2026-08-01 |
| Jack `BLACK` (GND) | `BLACK` | Breadboard **- rail** | |
| Breadboard + rail | `RED` | ULN2003 `+` pin | Motor power — **5V, not 3V3** |
| Breadboard - rail | `BLACK` | ULN2003 `-` pin | |
| ESP32 `GND` | `BLACK` | Breadboard **- rail** | 🔴 **COMMON GROUND — see below** |

### 🔴 The two power rules that protect the hardware

1. **Common ground is mandatory.** The ESP32 runs off USB, the motor off the adapter. If their
   grounds are not joined, the hall sensor reads garbage and the motor behaves randomly. This
   is the single most common cause of "everything worked, now nothing".
2. **Never connect the adapter to ESP32 `VIN` while USB is plugged into the laptop.** Two
   supplies fighting each other back-feeds your laptop's USB port. During bench work: motor
   from the adapter, ESP32 from USB, **grounds joined only.**
   *(To run the ESP32 off the adapter instead — for an untethered demo — see 3.2.)*

## 3.2 Running the ESP32 off the adapter (no laptop)

For the demo you want one plug, not a laptop tether. The ESP32 has a `VIN` pin that feeds its
onboard regulator, so it can share the motor's 5V rail.

**It is one extra wire.** The ground wire is already there as the common ground.

| From | Wire | To | Note |
|---|---|---|---|
| Breadboard **+ rail** | `RED` | ESP32 `VIN` | ⬅️ the only new connection |
| Breadboard **- rail** | `BLACK` | ESP32 `GND` | already present — common ground |

On the 30-pin DevKit V1 the pin is marked `VIN`. Some clones label it `V5` or `5V` — same pin,
at the corner next to `GND`.

### 🔴 Two mistakes that destroy the board

1. **Never USB and `VIN` at the same time.** Many cheap DevKit clones tie USB 5V and `VIN`
   together with no blocking diode, so a 3A adapter back-feeds the laptop's USB port — which is
   built to *source* current, not receive it.
2. **Never put 5V on the `3V3` pin.** `3V3` is the regulator's **output**, not an input.
   Feeding 5V there bypasses the regulator and puts 5V directly onto a 3.3V chip. Instant,
   permanent damage. **`VIN` is the only correct pin.**

### The working discipline: pull one wire

`VIN` is a Dupont wire into the header, so switching modes means unplugging it — nothing else.

| Mode | `VIN` wire | USB | Use for |
|---|---|---|---|
| **Flashing / serial monitor** | ⚠️ **unplugged** | plugged in | Development. Adapter may stay on for the motor; grounds stay joined. |
| **Standalone demo** | plugged in | ⚠️ **unplugged** | The 24 August demo. One plug, no laptop. |

**One wire in or out, never both connected.**

**Power budget:** ESP32 ~250mA + two motors ~500mA against a 3A adapter. Comfortable.

### ⚠️ If the ESP32 reboots when the motor moves

That is a **brown-out**, not a firmware bug. Sharing one supply means the motor's current
pulses dip the rail, and the ESP32 resets below ~2.8V.

**Fix:** a **470µF–1000µF electrolytic capacitor** across the `+` and `-` rails, physically
near the ESP32. About ₹10.

🔴 **Electrolytics are polarised.** The stripe on the can marks the **negative** leg → it goes
to the `-` rail. Fitted backwards it heats up and can burst.

⚠️ **This supersedes the "no capacitors needed" line in `ELECTRONICS_BOM.md`** — that was
correct while the ESP32 ran off USB with the motor on a separate supply. Sharing the rail
changes it. Buy one to have on hand; only fit it if you actually see resets.

## 3.3 Control — ESP32 to ULN2003

Use the **corrected** pins. Do not use 21/22.

| ESP32 | Wire | ULN2003 | Why this pin |
|---|---|---|---|
| `GPIO18` | `ORANGE` | `IN1` | Safe output |
| `GPIO19` | `YELLOW` | `IN2` | Safe output |
| `GPIO23` | `GREEN` | `IN3` | ⚠️ Was 21 — frees I2C `SDA` |
| `GPIO27` | `BLUE` | `IN4` | ⚠️ Was 22 — frees I2C `SCL` |

🔴 **Never use GPIO 0, 2, 5, 12, 15 for a motor coil.** They are *strapping pins*, sampled at
boot to decide how the chip starts. A coil pulling one of them low can stop the ESP32 booting,
and it looks like a dead board.

## 3.4 Sense — the hall sensor

| ESP32 | Wire | Hall module | Caution |
|---|---|---|---|
| `3V3` | `RED` | `VCC` | 🔴 **3V3, NEVER 5V.** ESP32 GPIOs are not 5V-tolerant. `AO` would output up to 5V and damage the pin. |
| `GND` | `BLACK` | `GND` | |
| `GPIO34` | `WHITE` | `AO` | Analog. Input-only pin on ADC1 — correct choice. |
| — | — | `DO` | Unused for one cell. Needed from 3 cells up (expanders have no ADC). |

## 3.5 Motor — the 28BYJ-48 plug

The motor's white 5-pin plug goes into the white socket on the ULN2003 board. **It only fits
one way.** Colours are listed for diagnosis only:

| Wire | Role |
|---|---|
| `RED` | Common / centre tap → +5V |
| `ORANGE` | Coil 1 |
| `YELLOW` | Coil 2 |
| `PINK` | Coil 3 |
| `BLUE` | Coil 4 |

⚠️ **If the motor buzzes and vibrates but does not turn,** the coil order is wrong, not the
wiring. Swap `IN2` and `IN3` in firmware before touching any hardware.

## 3.6 Navigation buttons — brain pod

| ESP32 | To | Config |
|---|---|---|
| `GPIO32` | Button "Prev" → `GND` | `INPUT_PULLUP`, active LOW |
| `GPIO25` | Button "Select" → `GND` | `INPUT_PULLUP`, active LOW |
| `GPIO17` | Button "Next" → `GND` | `INPUT_PULLUP`, active LOW |

**No resistors needed.** The ESP32 has internal pull-ups; the button only has to pull the pin
down to ground.

## 3.7 The whole circuit on one page

```
     5V 3A ADAPTER
          |
      [DC JACK]  red=+  black=-       [POLARITY VERIFIED 2026-08-01]
          |
     +----+--------------------+
     |                         |
   (+) rail                 (-) rail ------------------+
     |                         |                       |
     |                         |                    ESP32 GND   <-- COMMON GROUND
     |                         |                       |            (mandatory)
     +--> ESP32 VIN            |                       |    <-- standalone only,
     |    (see 3.2)            |                       |        NEVER with USB
  ULN2003 (+)            ULN2003 (-)                   |
     |                                                 |
  [ULN2003 BOARD]                              [ESP32 DEVKIT]
     IN1 <---------------- orange ---------------- GPIO18   powered by EITHER
     IN2 <---------------- yellow ---------------- GPIO19   USB *or* VIN (3.2)
     IN3 <---------------- green  ---------------- GPIO23
     IN4 <---------------- blue   ---------------- GPIO27
     |
   [white 5-pin socket]
     |
  [28BYJ-48 MOTOR] --> cam disc

  [HALL MODULE]  VCC <-- red ---- ESP32 3V3     [!] 3V3 ONLY
                 GND <-- black -- ESP32 GND
                 AO  --- white --> ESP32 GPIO34
```

---

# PART 4 — Why each component exists

Nothing here is decorative. One line each, so you can answer the panel.

| Component | Why it exists | What breaks without it |
|---|---|---|
| **ESP32 DevKit** | Decides *which* of the 64 cam states to show; serves the WiFi dashboard | No control at all |
| **ULN2003 board** | An ESP32 pin gives ~20mA at 3.3V; a motor coil wants ~200mA at 5V. This chip is seven electronic switches that bridge that gap. | Connect the motor direct and you **destroy the ESP32 pin** |
| **28BYJ-48 stepper** | Moves in countable half-steps. 4096/turn is a nominal starting value; the owned gearbox must be Hall-to-Hall calibrated. | No repeatable positioning |
| **Cam disc** | The mechanical decoder: one angle = one 6-dot pattern. Six tracks read simultaneously. | 6 separate actuators instead of 1 |
| **Hall sensor** | Finds absolute zero on power-up. A stepper knows *relative* steps, never where it actually is. | Every character wrong after a power cut |
| **Homing magnet (3x1mm)** | The thing the hall sensor sees | Nothing to home against |
| **Return springs** | Push each linkage back down onto the cam. Gravity alone is too weak at this scale. | Dots stick up and never retract |
| **DC jack + 5V 3A adapter** | USB alone cannot supply motor current safely | Brown-outs, ESP32 resets mid-move |
| **Brass heat-set inserts** | PETG threads strip after a few open/close cycles. Brass does not. | The box becomes single-use |
| **MCP23017** *(future only)* | Could turn five per-cell signals into a shared four-wire bus, but requires a 3.3V regulator/interface and measured carrier | Pin exhaustion at ~4 direct cells |

---

# PART 5 — Cautions and precautions

## Electrical

| # | Rule | Consequence if broken |
|---|---|---|
| 1 | 🔴 Hall `VCC` to **3V3**, never 5V | ESP32 input pin damaged |
| 2 | 🔴 **Common ground** between the two supplies | Random behaviour, garbage sensor readings |
| 3 | 🔴 Never adapter → `VIN` while USB is connected | Back-feeds the laptop USB port |
| 4 | ⚠️ Never a motor coil on GPIO 0, 2, 5, 12, 15 | ESP32 will not boot |
| 5 | ⚠️ De-energise coils when idle | Motor runs hot, wastes ~250mA holding still |
| 6 | ⚠️ Power off before rewiring anything | Shorts happen while probing live |

## Soldering

| # | Rule | Why |
|---|---|---|
| 1 | **Heat the joint; let the joint melt the solder** | Solder dabbed off the iron makes a cold joint — looks fine, fails later |
| 2 | Slide heat-shrink on **before** soldering | Everyone forgets this exactly once |
| 3 | Tug-test every joint | A good joint does not pull off. No glue rescues a bad one. |
| 4 | Practice on scrap first | Do not let the ESP32 be your first ever joint |
| 5 | ⚠️ Keep a **separate tip** for heat-set inserts | Melted plastic and brass ruin a tip for solder work |

## Mechanical / space

| # | Caution |
|---|---|
| 1 | 🔴 **14mm pocket, ULN2003 at ~12mm.** Dry-fit with real soldered wires before closing the box. |
| 2 | ⚠️ Superglue on the `dot_insert` gives you **no repositioning time**. Tape-align it dry first, then wick glue in from the edge. |
| 3 | ⚠️ Keep every adhesive away from the cam, the linkage feet and the dot holes. A drop of glue in the mechanism is worse than a bad solder joint. |
| 4 | ⚠️ FDM holes print 0.2–0.3mm undersize. Expect to drill pilots to size. |

---

# PART 6 — Shopping: what is left

## ✅ Already bought

Soldering iron · solder wire · wire stripper · super glue · multimeter · digital calipers ·
ESP32 · 28BYJ-48 + ULN2003 · hall module · 5V 3A adapter + jack · magnets 8x1mm ·
tactile switches · hookup wire · Dupont jumpers

## 6.1 Electronics still to buy

| # | Item | Spec | Why | Est. ₹ | Where |
|---|---|---|---|---|---|
| 1 | **Breadboard** | 830 tie points | 🔴 The whole demo runs on it. **This is the blocker.** | 100 | Local / online |
| 2 | **USB-C DATA cable** | Must carry data | Charge-only cables look identical and fail silently. **Test yours first.** | 150 | Have one? |
| 3 | **Heat-shrink assortment** | 2–6mm | Every joint. Non-negotiable. | 100 | Local |
| 4 | **Hot glue gun + sticks** | 20–40W | Strain relief. **Reworkable** — this is why it beats epoxy while the pin map can still change. | 250 | Local |
| 5 | Flux paste | Rosin, no-clean | Makes ULN2003 pins far easier | 100 | Local |
| 6 | Spare iron tip | Any, cheap | ⚠️ **Dedicated to heat-set inserts** | 100 | Local |
| 7 | Brass wool tip cleaner | — | Keeps the tip alive | 100 | Local |
| 8 | 2-way screw terminal blocks | 5mm pitch | Power spine without splicing | 40 | Local |
| 9 | **Electrolytic capacitor** | **470µF–1000µF, 10V or higher** | Brown-out insurance once the ESP32 shares the motor's rail — see 3.2. Buy it now, fit it only if you see resets. | 10 | Local |

**Electronics subtotal: ~₹950** (~₹800 if your USB-C cable does data)

## 6.2 What NOT to buy yet

| Item | Verdict |
|---|---|
| **MCP23017 expander** | ❌ **Not for 24 August, and not for two cells.** It earns its place at 3+ cells only. Order it when you commit to cell 3 — Robu.in, Element14 India, or Amazon. Local shops are hit-and-miss for DIP-28 logic; that is not a problem you have to solve now. |
| Resistors, capacitors, diodes | ❌ **Zero needed.** Flyback diodes are inside the ULN2003, pull-ups are inside the ESP32, regulators are on the DevKit. |
| ATmega328P / custom PCB | ❌ Cancelled. See `ELECTRONICS_PLAN.md` Part 1. |
| Level shifters | ❌ Hall runs at 3V3, so GPIO34 never sees 5V. |

## 6.3 Mechanism parts (order with the screws)

| # | Item | Spec | Qty | Est. ₹ |
|---|---|---|---|---|
| 1 | **Micro compression springs** | **2.0mm OD**, ~0.3mm wire, ~4mm free length | 6 + spares | 500 |
| 2 | **Homing magnet** | 🔴 **3mm dia x 1mm thick** neodymium | buy 10 | 120 |

🔴 **Not pen springs.** Pen springs are ~4mm OD; braille rows are 2.6mm apart. They physically
cannot fit.
🔴 **Not 3x2mm magnets.** The cam floor is only 2mm — a 2mm-thick magnet's pocket cuts clean
through it and destroys three cam tracks. 1mm thick leaves 0.8mm of floor and holds fine.
Your 8x1mm magnets are too wide in diameter for this job (they are for docking).

---

# PART 7 — Screws and inserts

## 7.1 The change that matters: brass heat-set inserts

The 2026-08-01 CAD update moved the box from *screwing into plastic* to **brass heat-set
inserts**. PETG threads strip after a few open/close cycles, and this box gets opened
constantly.

**You install them with the soldering iron you just bought.** Set ~230°C, press the insert in
slowly and straight, let it cool before removing the iron.

⚠️ **Use a cheap spare tip.** Brass and melted plastic contaminate a tip permanently for
soldering work.

## 7.2 What to order

Sizes taken from the CAD parameters, not guessed:

| # | Part | Size | Qty | CAD source |
|---|---|---|---|---|
| 1 | **Bolt** — top plate → standoffs → box | **M2.5 x 25mm**, socket cap or button head | 4 | `top_plate.scad` `screw_dia=3.2` clearance |
| 2 | **Heat-set insert** — box corner posts | **M2.5**, OD **3.5mm**, length **5.0mm** | 4 (buy 10) | `outer_box.scad` `insert_m25_dia=3.5`, `depth=5.5` |
| 3 | **Screw** — motor ears | **M4 x 5mm**, thread-forming; exact point/ear measurement still required | 2 | `base_plate.scad`; `base_interface_coupon`; **no M4x6/x10** |
| 4 | **Screw** — pod lid | **M2 x 8mm** *(or M2.5 x 8 — see 7.3)* | 2 | `esp32_pod_params.scad` |
| 5 | **Heat-set insert** — pod lid posts | **M2**, OD **3.2mm**, length **4.0mm** *(or M2.5 — see 7.3)* | 2 (buy 10) | `insert_m2_dia=3.2`, `depth=4.5` |

⚠️ **Measure the inserts when they arrive.** The CAD comments say so explicitly — insert OD
varies by brand, and the bore is a parameter precisely so it can be adjusted. If your M2.5
inserts measure 3.6mm rather than 3.5mm, that is a one-line CAD change, not a reprint decision.

**Search terms for onlyscrew.com:** "M2.5 socket cap screw 25mm", "brass threaded insert M2.5",
"M4 thread forming screw 5mm". If inserts are not stocked there, they are reliably available on Robu.in
and Amazon as "brass heat set insert assortment kit M2 M2.5 M3" (~₹350 for a mixed kit, which
also covers you for the measuring surprise above).

⚠️ I cannot check live stock on any of these sites. Treat the list as *what to search for*, and
if a size is genuinely unavailable, Part 7.3 tells you what can move.

## 7.3 Can we use one size for everything?

**Almost — you can get from three sizes to two.** Here is the honest analysis:

| Location | Now | Can it change? | Reasoning |
|---|---|---|---|
| Box corners | M2.5 x 25 | 🔒 **Keep** | Inserts and bores already in the CAD; changing means re-printing the box |
| Pod lid | M2 x 8 | ✅ **→ M2.5 x 8** | An M2.5 insert needs a 3.5mm bore. The post is 6.5mm dia, leaving **1.5mm of wall** — thinner than the 1.65mm it has now, but still enough for hot brass. |
| Motor ears | M4 x 5 only | 🔴 **Keep M4 diameter; coupon first** | Option A uses a through pilot. M4x5 is the only current candidate; do not use x6/x10 without measured ≥0.5mm cam clearance. |

### Recommendation

> **Standardise on M2.5 for everything structural. Keep M4 x 2 for the motor only.**
> Three sizes become two, and you buy **one** insert size instead of two.

**CAD change required — flagged for the CAD fork, NOT applied here:**

```
cad/scad/esp32_pod_params.scad
    insert_m2_dia    3.2  ->  3.5     M2.5 insert bore
    insert_m2_depth  4.5  ->  5.5     M2.5 inserts are longer
    lid clearance hole  2.2 -> 2.9    M2.5 clearance
```

⚠️ **Only worth doing if the pod shell and lid are not yet printed.** If they are printed,
buying two M2 screws is far cheaper than a reprint. **Check before changing anything.**

---

# PART 8 — Build order for the next two weeks

| # | Step | Needs | Blocked by |
|---|---|---|---|
| 1 | **Build the breadboard circuit** | Breadboard, Dupont | 🔴 **Only the breadboard.** No soldering. |
| 2 | Flash `breadboard_test.ino` | Data USB cable | Step 1 |
| 3 | Confirm motor turns + hall homes + dashboard loads | — | Step 2 |
| 4 | Solder header pins to the DC jack | Iron ✅ | Nothing |
| 5 | Solder ULN2003 wires flat | Iron ✅, heat-shrink | Nothing |
| 6 | Install brass inserts | Iron ✅, spare tip, inserts | Ordering |
| 7 | Dry-fit ULN2003 in the 14mm pocket | Printed box | Step 5 |
| 8 | Rehearse the demo script | — | Step 3 |

🔴 **Step 1 is the whole project's blocker and it needs nothing you do not already own except a
breadboard.** Everything else on this list is polish.

---

# PART 9 — Flagged for the CAD fork (do not fix here)

1. **Pod lid fastener standardisation** — M2 → M2.5, three parameters. Only if not yet printed.
   See Part 7.3.
2. **Hall module does not fit** the base plate — needs the bare TO-92 desoldered and a pocket
   that holds it. ⚠️ Check the sensor part number first (Part 1).
3. **DC jack has no thread or nut** — the pod lid cannot clamp it. Needs a retainer or a
   different jack.
4. **Electronics pocket is 14mm** with a ~12mm occupant. Working, zero margin. Verify with real
   soldered wires.
5. **Upper linkages** — the 24 August risk. Electronics does not depend on them.

---

## 10. The dock connector: why 5 pins for 4 signals

Solder the pogo connector in this order, on **both** dock faces:

```
   pin 1    pin 2    pin 3    pin 4    pin 5
   GND      SCL      5V       SDA      GND
   BLACK    YELLOW   RED      BLUE     BLACK
```

Pins 1 and 5 are both ground. This is deliberate. Do not reassign pin 5.

### Ground carries the whole chain

The brain sits at one end. The dock joint nearest the brain carries the current
of every cell downstream of it, and all of that current returns through ground.

| Cells refreshing together | Current at the first joint | Drop on 1 pin | Drop on 2 pins |
|---|---|---|---|
| 2 | 0.5 A | 50 mV | 25 mV |
| 8 | 2.0 A | 200 mV | 100 mV |

A pogo contact is about 100 milliohms. At 2 A a single pin dissipates 0.4 W in one
small spring contact, and 2.54 mm pogo pins are rated for only 1 A to 2 A. The
most loaded joint in the system is therefore the one closest to its limit.

The signal effect is more serious than the power effect, because ground is also
the I2C reference:

```
far cell pulls SDA low        0.2 V above its own ground
its ground sits               0.2 V above the brain ground
ESP32 sees                    0.4 V
ESP32 V_IL budget             0.825 V
```

Half of the noise margin is lost inside a connector. A drop on 5 V only weakens a
motor. A drop on ground corrupts the bus, and it does so only when several motors
move at the same time, which makes the fault intermittent and hard to find.

Double the ground and not the 5 V. Both carry the same current, but ground also
carries the signal reference.

### Orientation

Four docking magnets with opposite polarity prevent a reversed cell. This is the
primary defence and it is mechanical.

The pin order above is also symmetric about pin 3, so it gives a free second
defence. A reversed connector reads `GND SDA 5V SCL GND`: 5 V still meets 5 V and
ground still meets ground, and only SDA and SCL exchange places. The bus stays
silent until the cell is turned round, and nothing is damaged.

⚠️ The magnets stop a reversed cell **latching**. They do not stop it **touching**.
Pogo pins protrude and are spring loaded, so a hand that forces two repelling
faces together still makes contact for a moment. Do not force a cell that pushes
back. Turn it round.

### Do not reassign pin 5

| Proposed use | Why it is not needed |
|---|---|
| Detect which cells are attached | Scan I2C 0x20-0x27. The bus reports presence and position. |
| Shared INT for hall homing | An I2C poll takes about 0.3 ms. At 500 steps per second that is 0.15 of a step. Polling is fast enough. |
| Separate logic 5 V and motor 5 V | Same adapter and same ground, so no isolation is gained, and both rails lose half their capacity. |
| Auto-addressing without jumpers | Needs a latch in every cell, to replace three jumpers set once. |

Spare capacity for future features is on the MCP23017, not on the connector. Five
of its 16 pins are used: four to the ULN2003 and one to the hall sensor. A button,
a touch pad, a status LED or a second sensor goes on the 11 free pins and uses the
bus that already exists.

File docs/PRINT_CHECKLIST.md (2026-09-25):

# Braillix print checklist - current release

**Use:** [`PRINT_RELEASE_2026-08-19.md`](PRINT_RELEASE_2026-08-19.md)

This replaces the historical v5 prototype checklist. Do not print obsolete files such as
`braille_cam2.stl`, `linkage_comb.stl`, the old panel-jack pod, or the old `print_batch` ZIP.

## Checked PETG files

- [ ] `motor_cam_socket_coupon.gcode`
- [ ] `motor_collar_wire_coupon.gcode`
- [ ] `hall_island_coupon.gcode`
- [ ] `base_interface_coupon.gcode`
- [ ] `pod_header_usb_coupon.gcode`
- [ ] `pigtail_slot_coupon.gcode`
- [ ] `pogo_receiver_coupon.gcode`
- [ ] `top_interface_coupon.gcode`
- [ ] `hardware_fit_coupon.gcode`
- [ ] `cam_linkage_test_fixture.gcode` if the resin test set and spring are available
- [ ] `mid_plate.gcode` after the first coupon prints cleanly

All are under `printing/gcode_kobra_neo_checked` and validated for the stock Kobra Neo:
0.16 mm, 5 walls, 40% infill, PETG 235/230 C, bed 80 C, supports off, no arcs.
Speeds are 30/45/60/20/150 mm/s (outer/inner/infill/first/travel) with effective
1 mm retraction at 35 mm/s.

## Required fit results

- [ ] motor double-flat socket selected without force
- [ ] motor sits flat on the bridged seat coupon without rocking
- [ ] motor can sits flat in collar and the blue lead housing exits without pinching
- [ ] exact Hall island roof does not sag and switches through the intended magnet gap
- [ ] actual M4 screw pilot selected without splitting/stripping
- [ ] actual M2.5 bolt bore selected in a Ø6 x 12 mm post without splitting
- [ ] pigtail passes the smallest selected cable-only slot without insulation damage
- [ ] M2.5 shank/head diameter/depth selected
- [ ] real resin dot insert fits selected pocket
- [ ] real female headers, pre-soldered tails, ESP32, and USB-C plug pass the pod coupon
- [ ] heat-set insert bore selected using purchased insert
- [ ] 8 x 1 mm magnet pocket selected
- [ ] Hall-body depth selected
- [ ] printed pogo receiver size measured
- [ ] exact TPU 95A spool identified before any end-cap G-code

## Mechanism evidence

Use [`MECHANISM_BENCH_TEST.md`](MECHANISM_BENCH_TEST.md).

- [ ] dot-5 dry travel passes in both directions
- [ ] dot-6 dry travel passes in both directions
- [ ] down height is flush within +/-0.10 mm
- [ ] up travel is 0.80 +/-0.10 mm for the current cam
- [ ] each linkage completes 50 spring cycles in both directions
- [ ] no scoring, cracking, whitening, dust, or coil damage
- [ ] high/low dwell is stable
- [ ] worst simultaneous transition has at least 2x motor torque reserve

## Production parts on HOLD

- [ ] top plate - wait for actual screw and insert coupon
- [ ] Option-A production cam - candidate socket valid in CAD; pending resin/ramp/spring/torque proof
- [ ] Option-A base plate - pending Hall, motor, M4, and standoff coupon results
- [ ] Option-A outer box and pod - pending hardware/electrical fit despite corrected height
- [ ] linkage/dot insert - pending real resin motion test
- [ ] nav caps - supported/angled resin only
- [ ] pogo end cap - TPU 95A receiver/retention test only

Do not mark the product print-ready merely because the STL is manifold or the slicer succeeds.

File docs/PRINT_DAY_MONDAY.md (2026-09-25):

# Braillix print day - current plan

**Authority:** [`PRINT_RELEASE_2026-08-19.md`](PRINT_RELEASE_2026-08-19.md)

Do not use the old `print_batch` folder, old 3-wall G-code, or any enclosure/mechanism G-code
outside the current checked folder.

## Before printing

1. Dry NuMaker PETG HS at 60-65 C for 4-6 hours.
2. Clean the bed and nozzle.
3. Confirm the printer is the stock Anycubic Kobra Neo with a 0.4 mm nozzle.
4. Copy only the eight files currently inside `printing/gcode_kobra_neo_checked`.
5. Keep the motor unpowered during all shaft-coupon fitting.

## Print order

1. `motor_cam_socket_coupon.gcode`
2. `base_interface_coupon.gcode`
3. `pigtail_slot_coupon.gcode`
4. `pogo_receiver_coupon.gcode`
5. `top_interface_coupon.gcode`
6. `hardware_fit_coupon.gcode`
7. `cam_linkage_test_fixture.gcode` if the resin test set and real spring are available
8. `mid_plate.gcode` after the first coupon proves the PETG/profile is behaving normally

The full top plate is on HOLD until the real M2.5 screw and real resin dot insert pass the
top-interface coupon. The production cam, base, box, pod, linkage set, dot insert, nav caps, and
TPU end cap are also on HOLD for the reasons in the release document.

## Stop immediately if

- the first layer lifts or separates;
- walls split or warp;
- a required hole/slot prints closed;
- the nozzle hits the part;
- the printer emits unsupported G2/G3 errors;
- the material pops/crackles from moisture;
- any shaft coupon needs force, hammering, heat, or power.

A failed coupon is a successful warning. Do not continue to the larger dependent part.

## Record after printing

Photograph and write down:

- selected motor double-flat size;
- motor-seat roof flat/rock-free result;
- selected M4 pilot and M2.5 standoff bore;
- selected pigtail cable-slot size;
- selected M2.5 shank, head diameter, and head depth;
- selected resin-insert clearance;
- selected heat-insert bore;
- selected magnet pocket;
- selected Hall depth;
- measured pogo receiver opening.

For the real cam/linkage/spring test, follow
[`MECHANISM_BENCH_TEST.md`](MECHANISM_BENCH_TEST.md) and record travel, 50-cycle return behavior,
damage, and peak pull force. Do not release the full mechanism from a visual fit alone.

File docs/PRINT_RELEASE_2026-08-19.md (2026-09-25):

# Braillix print release - 2026-08-19

Updated 2026-08-20 after the measured-stack and print-profile repair pass.

## Verdict

**Do not print the complete product set yet.** Option A now closes the measured motor/cam stack in
source, but the socket, Hall island, ramps, springs, headers, and enclosure hardware still need the
small physical gates below. The old default stack remains intentionally unreleased.

The checked PETG folder contains exactly eleven files. They are either small fit tests, a mechanism
test fixture, or the stack-independent mid plate. No enclosure, production cam, base plate, pod,
or final top plate is released.

## Tomorrow's print order

### Required fit tests

1. `motor_cam_socket_coupon.gcode` - 32m 26s / 2.36 g
2. `hall_island_coupon.gcode` - 21m 06s / 1.90 g
3. `motor_collar_wire_coupon.gcode` - 1h 08m 48s / 7.46 g
4. `base_interface_coupon.gcode` - 1h 32m 42s / 9.05 g
5. `pigtail_slot_coupon.gcode` - 53m 03s / 5.77 g
6. `pod_header_usb_coupon.gcode` - 1h 42m 55s / 11.37 g
7. `pogo_receiver_coupon.gcode` - 1h 35m 30s / 12.79 g
8. `top_interface_coupon.gcode` - 1h 44m 59s / 10.70 g
9. `hardware_fit_coupon.gcode` - 2h 48m 16s / 20.03 g

Stop after any print with poor first-layer adhesion, separated walls, closed holes, heavy stringing,
or visible warping. A bad coupon means the larger part is not safe.

### Mechanism test fixture

10. `cam_linkage_test_fixture.gcode` - 2h 45m 34s / 18.80 g

This fixture is useful only with
`cad/stl/cam_linkage_test_resin_set.stl`, one real 2 mm OD spring, and the procedure in
[`MECHANISM_BENCH_TEST.md`](MECHANISM_BENCH_TEST.md). The resin set contains the real cam,
dot-5 linkage, dot-6 linkage, and dot insert. It is intentionally STL-only because the resin
printer, resin, and service settings are not specified.

### Stack-independent production part

11. `mid_plate.gcode` - 1h 25m 35s / 8.96 g

Print the mid plate only after the first coupon proves the PETG/profile is behaving normally.
Its geometry already uses the measured 28.1 mm motor body, -7.5 mm body offset, and 34.7 mm ear
spacing, and it survives the pending +4 mm upper-stack option.

## Checked PETG contract

All eleven checked G-code files were freshly sliced from the current STLs with:

- NuMaker PETG HS: 235 C first layer / 230 C normal
- bed 80 C
- layer height 0.16 mm
- 5 wall loops
- 40% infill
- 6 bottom + 6 top shell layers
- 8 mm brim
- top-surface ironing
- supports disabled
- no G2/G3 arc commands
- outer / inner / infill / first-layer / travel speeds = 30 / 45 / 60 / 20 / 150 mm/s
- effective direct-drive retraction = 1 mm at 35 mm/s; startup and shutdown retracts use the same limit

`tools/validate_print_assets.py` verifies the exact checked manifest, embedded settings,
Kobra Neo motion envelope, closed/manifold topology, expected component count, each G-code's
source-STL SHA-256, independent fresh OpenSCAD equality, and explicit Option-A provenance. The
release command requires both the fresh-render directory and Option-A candidate directory.

## Coupon maps and acceptance

### Motor/cam socket coupon

The one-, two-, and three-hole tabs are 3.1, 3.2, and 3.3 mm double-flat sockets.

Use the smallest socket that:

- slides fully over the unpowered motor shaft;
- reaches and sits flat on the measured 9 mm collar;
- does not split, whiten, or require hammering;
- can still be removed using the tab.

Do not heat, glue, hammer, or power the motor during this test.

### Motor collar/wire coupon

Seat the owned motor can in the Ø29.5 collar with its blue wire housing aimed through the +Y notch.
The can must sit flat without forcing, rocking, pinching the leads, or lifting the collar. This test
also selects whether the collar needs additional radial clearance before the full mid plate is used.

### Hall-island coupon

This is an exact section of the Option-A base: 4.5 x 3.5 mm underside tunnel, 1 mm lead channel,
0.4 mm PETG roof, and 0.5 mm raised island. Reject it if the roof sags, the bare Hall body cannot
reach the roof, or its leads force it downward. Power the Hall from ESP32 3V3 and prove switching
through the intended 3 x 1 mm magnet before releasing the full base.

### Base-interface coupon

This has three disconnected pieces, left to right:

- Ø34 puck: real Ø29 x 1.5 mm underside motor seat around the Ø10 shaft opening. Reject it if the
  bridged locating roof sags enough that the motor cannot sit flat without rocking.
- 5 mm bar: through M4 pilot holes 3.3 / 3.4 / 3.5 mm. Use the smallest that accepts an M4x5
  thread-forming screw with controlled thread formation and no whitening, splitting, or stripped
  PETG. Do not use M4x6/x10 without a measured ear/point stack proving >=0.5 mm cam clearance.
- three Ø6 x 12 mm posts: M2.5 clearance bores 2.9 / 3.0 / 3.1 mm. Use the smallest free-sliding
  hole that does not split the slender post. These reproduce the proposed taller Option-A posts;
  testing them does not authorize the production stack change.

### Pigtail cable-slot coupon

The clipped corner marks the 5 x 3 mm end. The middle slot is the current 6 x 4 mm CAD value; the
other end is 7 x 5 mm. Pass only the loose red/black leads, never the barrel body. Select the
smallest opening that accepts both leads without scraping, pinching, whitening, or cutting their
insulation. Record the selected width x height before regenerating the pod lid.

### Pogo receiver coupon

Left to right, the upright bridged slots are:

- 10.0 x 8.0 mm - current production CAD;
- 10.2 x 8.2 mm;
- 10.4 x 8.4 mm.

All reproduce the real 4 mm enclosure wall. Accept a slot only if its roof prints open without
cutting structural material and the measured opening is usable. The end cap itself remains TPU
95A only. No TPU G-code is released until the exact spool is known.

### Top-interface coupon

The large keyed piece tests the actual M2.5 x 25 screw.

- clipped corner = top-left;
- columns left to right = counterbore diameters 5.4 / 5.6 / 5.8 mm;
- rows top to bottom = effective depths 1.3 / 1.5 / 1.7 mm;
- bottom plain holes left to right = 3.0 / 3.2 / 3.4 mm shank clearance.

Select the smallest/shallowest station where the real screw drops through, the head seats flat,
and a finger/straightedge does not catch it.

The separate notched strip tests the real resin dot insert:

- notched end is left;
- left to right total clearance = 0.2 / 0.4 / 0.6 mm;
- production CAD currently uses 0.2 mm total, only 0.1 mm per side.

Select the smallest pocket where the insert seats without forcing or cracking and can be removed
before gluing. The held top plate must be updated/re-sliced if the selected station is not the
current 5.6 x 1.5 mm screw seat and 0.2 mm insert clearance.

### Pod header/USB coupon

Dry-fit both actual 1x15 female headers, the owned 30-pin USB-C ESP32, the intended pre-soldered
tails, and the actual USB-C plug. The board must insert/remove without bending pins, tails must fit
in the 5 mm under-deck space, and the cable must mate without pushing the board. This coupon does
not release the full pod until it passes.

### Hardware-fit coupon

- top-left row 3.1 / 3.3 / 3.5 / 3.7: heat-set insert bores;
- bottom-left row 3.1 / 3.2 / 3.3: shaft double-flat clearances;
- top-right row 8.2 / 8.4 / 8.6: 8 x 1 mm magnet pockets;
- bottom-right row 1.7 / 1.8 / 1.9: Hall-body pocket depths.

Do not melt an insert or glue a magnet into a production shell before choosing the coupon fit.

## HOLD - do not manufacture as final parts

| Part | Blocking reason |
|---|---|
| `top_plate` | G-code moved to `printing/gcode_HOLD_fit_unproven`; real screw head and resin insert must pass the top-interface coupon |
| `braille_cam` | Option-A socket/cap is statically valid, but resin socket fit, real ramps, springs, Hall homing, and torque remain unproven; legacy default is invalid |
| `base_plate` | Option-A stack is statically valid; Hall island, motor seat, M4 pilot, and slender post fits still require coupons |
| `outer_box` | Option-A height is available only in the candidate export; active dock carrier and ULN2003 retention remain hardware-gated |
| `esp32_pod_shell` | raised header deck and 8-wire service route exist, but actual headers/USB and final electronics retention are unmeasured; four-contact pogo architecture is not electrically defined |
| `esp32_pod_lid` | inline-pigtail geometry is corrected, but cable-slot pull/fit and complete pod assembly are pending |
| `linkage` | final release needs resin dot-5/dot-6 ramp, spring-return, binding, and torque evidence |
| `dot_insert` | final release needs real resin fit, dome sliding, spring insertion, and 50-cycle evidence |
| `nav_cap` | supported/angled resin only; not a support-free PETG part |
| `pogo_end_cap` | TPU 95A only; receiver size and barb retention require a real insertion/removal test |

Old 3-wall G-code is quarantined under `printing/gcode_HOLD_unvalidated`. The old
`print_batch` folder is historical and marked DO NOT USE.

## Confirmed corrections already applied

- motor body offset changed from -8.0 to measured -7.5 mm;
- motor ear spacing changed from 35.0 to measured 34.7 mm;
- top counterbores now provide 1.5 mm below the recessed reading surface;
- outer-box pogo windows are symmetric and fully through;
- pod dock-wall antenna subtraction that left 0.5 mm skin was removed;
- guessed unsupported panel-jack cradle was removed;
- pod lid now uses the owned inline pigtail with a 6 x 4 mm cable slot and tie post;
- pogo end cap now has a hollow TPU tongue and real barb geometry;
- Option A adds a measured 7.7 mm double-flat socket, 0.5 mm roof, collision-cleared central boss,
  +4 mm upper stack, through M4 pilots, and a 0.5 mm Hall running gap;
- mid-plate clearance and motor-wire notch were enlarged and reproduced in a collar coupon;
- pod headers now sit on raised prewired decks with a separate header/USB coupon;
- cell/pod service windows are shared 10 x 8 mm geometry, while the direct demo uses an 8-wire rear harness;
- stale 3-wall outputs were quarantined;
- stack-independent motor, base, top, hardware, pogo, pigtail, and mechanism test assets were added.

## Option A candidate status

The non-destructive Option A repair is implemented behind `stack_repair_raise=4`:

- keep the motor shaft intact;
- seat the cam hub on the measured 9 x 2 mm collar;
- raise the upper mechanism and matching enclosures by exactly 4 mm;
- rebuild the cam with a true 7.7 mm blind double-flat socket and central roof;
- raise the Hall sensor on an island with 0.5 mm mechanical and 0.9 mm magnetic separation.

Authoritative candidate STLs live only in `cad/stl_option_a_candidate` with a manifest that records
the +4 mm variant and hashes. Plain/default OpenSCAD exports remain legacy and are not printable
production parts. Do not cut the owned shaft.

After the chosen stack repair, regenerate every dependent STL, repeat the real mechanism bench
test, verify Hall switching at the real gap, select coupon dimensions, and only then create the
final production G-code manifest.

The current 0.80 +/- 0.10 mm dot lift is an intentionally oversized teaching-prototype target,
not a standards-compliant Braille claim. Standard tactile-height redesign is a separate gate.

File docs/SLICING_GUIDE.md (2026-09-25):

# Braillix — Slice It Yourself (Anycubic Kobra Neo)

> **CURRENT RELEASE GATE - 2026-08-19:** Do not manually slice production parts from this historical
> guide for tomorrow's run. Use only `printing/gcode_kobra_neo_checked/` and the exact contract in
> `PRINT_RELEASE_2026-08-19.md`. The checked profile is 0.16mm, 5 walls, 40% infill, 6/6 shells,
> 8mm brim, PETG 235/230C, bed 80C, supports off, and arc fitting off.
> A complete guide to producing your own G-code on your PC, so the lab just loads the file.
> Written 2026-07-30 for: **Anycubic Kobra Neo · 0.4mm nozzle · PETG · lab accepts G-code.**

---

## Why your first print failed — the three real causes

| What you saw | Actual cause |
|---|---|
| Supports welded in, couldn't pluck them out | Supports were switched **on** with PLA-tuned settings. PETG bonds across a gap that PLA snaps at. **These parts need no supports at all.** |
| Screw columns snapped | Not enough **walls**. On a Ø7.8mm column, walls are almost the whole part — infill barely matters. |
| Filament strings between travel moves | **Stringing.** Wet PETG + too-hot nozzle + wrong retraction. The Kobra Neo is **direct drive**, so most online retraction advice (5–6mm, meant for Bowden) is wrong and makes it worse. |

None of these are your fault, and only one is the teacher's — they're the default settings.

---

# PART 1 — Software

## Install OrcaSlicer (recommended)

**Download:** <https://github.com/SoftFever/OrcaSlicer/releases> → the `.exe` for Windows.

**Why OrcaSlicer over Cura, for your situation:**
- Anycubic Kobra profiles are **built in** — far fewer ways to get the machine setup wrong
- Has **built-in calibration tests** (retraction, temperature) that directly fix your stringing
- Per-object settings are much easier — which you need for the screw columns

> Cura also works and your teacher may know it better. Cura equivalents for every setting are
> in **Appendix A** at the end.

## First-run setup

1. Launch OrcaSlicer → the setup wizard appears
2. **Printer** → search `Anycubic` → pick **Kobra Neo** (or **Kobra 2 Neo** — check the machine's
   boot screen for which one). If it is genuinely absent, use **Appendix B** to add it manually.
3. **Filament** → tick **Generic PETG**
4. Finish

**Verify the machine settings** (top-right printer dropdown → the pencil/edit icon):

| Setting | Value |
|---|---|
| Bed size | 220 × 220 mm |
| Max height | 250 mm |
| Nozzle diameter | **0.4 mm** |
| Extruder type | **Direct Drive** ← this one matters most |

---

# PART 2 — The settings that fix your problems

Switch OrcaSlicer to **Advanced** mode (top-right dropdown: Simple / Advanced / Expert →
choose **Advanced**), or you won't see half of these.

## 2.1 Quality tab

| Setting | Value | Why |
|---|---|---|
| Layer height | **0.16 mm** | Current checked coupon profile. |
| First layer height | **0.24 mm** | Current checked coupon profile. |
| **Wall loops** | **5** | 🔴 **THE FIX FOR YOUR BROKEN SCREW COLUMNS.** Default is 2. At 0.4mm each, 5 walls = 2mm of solid shell — on a Ø7.8mm boss that is nearly the entire column. |
| Top shell layers | **6** | Current checked coupon profile. |
| Bottom shell layers | **6** | Current checked coupon profile. |
| Seam position | **Aligned** | Puts the layer-change blob in a consistent line instead of scattering it |

## 2.2 Strength tab

| Setting | Value | Why |
|---|---|---|
| Sparse infill density | **40 %** | Current checked coupon profile; do not reduce before fit tests pass. |
| Sparse infill pattern | **Gyroid** | Strong in all directions, no sharp direction changes to shake the printer |

## 2.3 Support tab — 🔴 TURN IT ALL OFF

| Setting | Value |
|---|---|
| **Enable support** | **OFF (unchecked)** |

**Nothing in these parts needs support, for two separate reasons:**

**1. The overhangs that could be solved by shape, are.** Magnet pockets are **teardrop-shaped**
(a 45° peak instead of a round top) so they hold themselves up. Corner bosses have **gusset
cones** widening toward the floor. Neither leaves anything to remove.

**2. Everything else is just a normal bridge.** Every hole in a wall is a 10–15mm span, and a
well-cooled printer bridges **20–30mm** unaided:

| Opening | Span | |
|---|---|---|
| Pogo slots (×2) | 10mm | routine bridge |
| Wire exit | 15mm | routine bridge |
| USB cutout (pod) | 10mm | routine bridge |
| Nav holes (×3) | 4.2mm | trivial |

> **Note (v7.4):** earlier versions modelled thin sacrificial bridges into these holes. They
> have been **removed** — they were redundant at these spans, and if you forgot to snap them
> out the pogo pins and wires could not pass through. **There is now nothing to remove from
> any hole.** The STL is exactly the finished part.

**If you print with supports ON, the slicer fills the whole 60×60×50mm cavity with lattice
that you cannot reach.** That is exactly what happened to you.

## 2.4 Speed tab

| Setting | Value | Why |
|---|---|---|
| Outer wall | **30 mm/s** | Slower = better surface |
| Inner wall | 45 mm/s | |
| Sparse infill | 60 mm/s | |
| **Travel** | **150 mm/s** | Fast travel = less time to ooze = less stringing |
| First layer | **20 mm/s** | Adhesion |

## 2.5 Filament tab — 🔴 THE STRINGING FIX

| Setting | Value | Why |
|---|---|---|
| Nozzle temperature | **230 °C normal / 235 °C first layer** | Matches the checked NuMaker PETG profile. |
| Bed temperature | **80 °C** | |
| **Retraction length** | **1.0 mm** | 🔴 **Kobra Neo is DIRECT DRIVE.** Most guides say 5–6mm — that is for Bowden printers and will jam yours. |
| Retraction speed | **35 mm/s** | |
| Z-hop when retracting | **OFF / 0 mm** | Matches the checked machine profile; change only after a calibration test. |
| Wipe on retract | **ON** | |

### 🔴 The thing that actually causes stringing: wet filament

**PETG absorbs moisture from the air, and Patiala is humid.** Wet filament strings no matter
how perfect your settings are — the water boils out of the nozzle as steam.

**Dry it before printing:**
- Oven at **60–65 °C for 4–6 hours** (door slightly ajar). Do **not** exceed 70 °C or the spool warps.
- Or a food dehydrator at 65 °C
- Store it afterwards in a sealed box with silica gel

If the filament crackles or pops as it extrudes, it is wet. That is your problem, not settings.

---

# PART 3 — Making JUST the screw columns solid

You asked exactly the right question: you want the screw columns denser without making the
whole part 100 % infill. This is a **modifier**.

**Honest answer first:** with **Wall Loops = 5** the columns are already nearly solid, and that
alone will probably fix the breakage. Try that before bothering with modifiers.

If you still want them fully solid:

1. Load `outer_box.stl`, **right-click** the model
2. **Add modifier** → **Box**
3. A translucent box appears. In the right-hand **Object list**, select it.
4. Set its **size and position** so it encloses one corner boss:
   - Size: `12 × 12 × 40` mm
   - Position: `X = 26`, `Y = 21`, `Z = 20` (that is one boss; the four are at X ±26, Y ±21)
5. With the modifier still selected, in the parameter panel below, click **+ Add setting** →
   **Strength** → **Sparse infill density** → set it to **100 %**
6. **Repeat for the other three corners** (or select the modifier, Ctrl+C / Ctrl+V, and change
   the position)

Anything inside that box prints at 100 % infill; everything else stays at the checked 40 %.

> The same trick works for the mid-plate ledge or any other feature you want beefed up.

---

# PART 4 — Orientation, part by part

🔴 **`outer_box` must be printed OPEN SIDE UP.** The rim sits on the bed, cavity facing the
ceiling.

> A previous version of our own notes said to flip it rim-down. **That was wrong and I've
> corrected it.** Nothing can bridge a 60mm cavity, and flipping it hangs the four Ø7.8 × 37mm
> bosses tip-first in mid-air — which is very likely why yours snapped.

| Part | Orientation | Supports | Layer | Infill | Walls |
|---|---|---|---|---|---|
| **outer_box** | **Open side UP**, solid floor on bed | ❌ OFF | 0.16 | 40 % | **5** |
| **base_plate** | Flat, standoffs UP | ❌ OFF | 0.16 | 40 % | 5 |
| **mid_plate** | Flat, collar UP | ❌ OFF | 0.16 | 40 % | 5 |
| **top_plate** | HOLD pending top-interface coupon | ❌ OFF | 0.16 | 40 % | 5 |
| **esp32_pod_shell** | HOLD; open side UP, solid floor on bed | ❌ OFF | 0.16 | 40 % | **5** |
| **esp32_pod_lid** | HOLD; flat, ridges UP | ❌ OFF | 0.16 | 40 % | 5 |
| **pogo_end_cap** | HOLD; TPU 95A only, spool-specific profile required | ❌ OFF | — | — | — |

---

# PART 5 — Producing the G-code

1. **Load** the STL: `File → Import → Import STL`, pick e.g. `cad/stl/outer_box.stl`
2. **Orient it** per Part 4. `Rotate` tool on the left toolbar; hold the mouse on a face and
   use **Place on face** to drop a chosen face onto the bed.
3. **Check the settings** from Parts 2–3
4. **Slice** — the `Slice plate` button, bottom right
5. **Inspect the preview.** This is the step that would have saved your first print:
   - Drag the **vertical layer slider** on the right up and down
   - Look for **blue/teal support material** — if you see any, supports are still on. Turn them off.
   - Check the bridges over the pogo slots and wire exit actually appear as thin flat spans
   - Confirm the corner bosses look solid, not hollow
6. **Export G-code** → save to an SD card as e.g. `outer_box.gcode`
7. Hand the SD card to the lab. They just load and print.

> **Print ONE released coupon first** — `motor_cam_socket_coupon` is the shortest useful gate. Do not print
> `pogo_end_cap` from the PETG profile; it remains TPU-only and spool-gated. A coupon tells you
> whether your settings are right before you commit 3 hours to the box.

---

# PART 6 — After the print

| Job | How |
|---|---|
| Clean the screw holes | The M2.5 pilots print ~0.2–0.3mm undersize. Run a **2.5mm drill bit** through by hand — do not power-drill, you'll melt it. |
| Magnet pockets | Should be clear (teardrop shape). If tight, a **8mm** bit turned by hand. |
| Stringing wisps | Snip with flush cutters, or wave a heat gun / lighter **quickly** past them (do not hold it there) |
| Layer lines | 400 → 800 grit wet sandpaper if you care cosmetically |

---

# PART 7 — How to close the Brain Pod

The pod is two printed parts: **shell** (the open box) and **lid**.

```
                    ┌─────────────────────┐
                    │   POD LID           │  ← 3 ridges on top (tactile ID)
                    │  o               o  │  ← 2 screw holes at X = ±27.5
                    └──┬───────────────┬──┘
                       │               │      the lid's front/back SKIRT
   ┌───────────────────┴───────────────┴───┐  drops over the shell and
   │  POD SHELL                            │  self-locates it
   │    [ESP32 sits on header strips]      │
   │  ●                                 ●  │  ← 2 screw BOSSES, also at X = ±27.5
   └───────────────────────────────────────┘
```

**Steps:**
1. ESP32 plugged into its header strips inside the shell, wires routed
2. Lower the lid straight down — the **skirt on the front and back edges** slides over the
   shell walls and centres it. The left/right ends stay flush (those are the docking faces).
3. The two holes line up over the two bosses
4. Drive **2 × M2 × 8mm self-tapping screws** down through the lid into the bosses

**Screw length matters:** the lid is 4mm thick and the boss is 8mm deep. An **M2×8** leaves
4mm of thread biting into the boss. An M2×6 only gives 2mm and will strip out — do not use it.

**No glue.** The pod is meant to open so you can swap the ESP32.

---

# Appendix A — Cura equivalents

| OrcaSlicer | Cura |
|---|---|
| Wall loops | **Wall Line Count** |
| Sparse infill density | **Infill Density** |
| Enable support | **Generate Support** |
| Retraction length | **Retraction Distance** |
| Top shell layers | **Top Layers** |
| Modifier box | **Per Model Settings** → *Modify settings for overlaps* |
| Slice plate | **Slice** |

In Cura you must also set the cog icon → **Setting Visibility → Expert** or most of these stay hidden.

# Appendix B — Manual Kobra Neo profile (only if it's not built in)

Add Printer → Custom / Add local printer:

| | |
|---|---|
| Build volume | 220 × 220 × 250 mm |
| Nozzle | 0.4 mm |
| Filament | 1.75 mm |
| Extruder | **Direct drive** |
| Bed shape | Rectangular, origin front-left |
| Firmware / G-code flavour | **Marlin** |
| Start G-code | leave the default Marlin one |

---

# The five-line version

1. **Supports OFF** — every overhang is already handled in the CAD
2. **Wall loops = 5** — this is what fixes the broken screw columns
3. **Retraction 1.0mm** — Kobra Neo is direct drive, not Bowden
4. **Dry the PETG** — 60–65 °C for 4–6 h; wet filament strings regardless of settings
5. **outer_box prints OPEN SIDE UP** — never rim-down

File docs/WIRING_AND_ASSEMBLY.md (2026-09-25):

# Braillix v6.1 — Wiring & Assembly Guide

> **CURRENT RELEASE GATE - 2026-08-19:** The wiring tables remain useful, but the historical full
> assembly sequence is retired. Do not trim the shaft, press the current cam, use bearing balls,
> drop springs into the PETG top plate, or install unretained pogo/header hardware. Use
> `PRINT_RELEASE_2026-08-19.md`, `ASSEMBLY_BIBLE.md`, and `MECHANISM_BENCH_TEST.md` as the current
> authority.

## Prototype Cell Electronics (no muscle board yet) — ULN2003 module fit

The off-the-shelf ULN2003 driver module DOES fit the 36×46×14mm electronics pocket,
**but only with low-profile wiring** (measured: ~20mm tall with vertical Dupont jumpers
plugged in — too tall; ~12mm with wires soldered flat):

1. Cut the female Dupont housings off 6 jumper wires (IN1–IN4, +5V, GND); strip ~3mm.
2. Solder each wire **flat against its header pin, lying parallel to the board** (bend the
   wire 90° at the pin base, then solder). Beginner-level joint — tin pin, tin wire, touch.
3. Press the ULN2003 DIP chip fully down into its socket (it often sits raised).
4. Lay the board **flat on the pocket floor** (NOT on the 4mm muscle-board bosses), with the
   JST/header edge toward the **front-right (+X, −Y) corner** — the mid-plate has a relief
   slot there (v6.1) giving the JST plug extra headroom.
5. The white JST motor plug inserts before the mid-plate goes in.

When the custom muscle board is fabricated later, it mounts on the 4 M2 bosses as designed.

## Pogo Daisy-Chain Pinout (4-pin, same everywhere)
```
Pin 1 = +5V    Pin 2 = GND    Pin 3 = SDA    Pin 4 = SCL
```
```
[5V/3A adapter]
      |
      v
+-----------+   pogo    +--------+   pogo    +--------+
| BRAIN POD |<--------->| CELL 1 |<--------->| CELL 2 |-->...-->[end cap]
| (ESP32)   | 4 wires   |        | 4 wires   |        |
| I2C master| 5V/GND/   | I2C    |           | I2C    |
| + buttons | SDA/SCL   | slave  |           | slave  |
+-----------+           | 0x20   |           | 0x21   |
                        +--------+           +--------+
```

## Per-Cell Wiring (Muscle Board Connectors)

| Connector | Pins | From | Color | Routing |
|---|---|---|---|---|
| J1 (pogo) | 4: 5V,GND,SDA,SCL | Both pogo connectors (bridged) | Red,Black,Blue,Yellow | Down wall guides -> mid-plate notches -> pocket |
| J2 (motor) | 5: coils A-D + COM | 28BYJ-48 (JST-XH plug) | White 5-pin | Motor slot (x=-8,y=20) -> pocket |
| J3 (hall) | 3: VCC,GND,SIG | SS49E hall sensor | Red,Black,Green | Base plate +Y channel -> mid-plate +Y notch -> pocket |
| J4 (ISP) | 6 | AVR programmer | 2x3 ribbon | Temporary - remove after flashing |

Wire count per cell: **12 permanent** (4 pogo + 5 motor + 3 hall)

### Pogo Bridge (inside each cell)
Each cell has -X springs and +X pads. Bridge both to J1 (3-way splice per net):
```
-X pogo spring --+-- J1 pin --+-- +X pogo pad
                 (same for all 4 nets)
```

## ESP32 Brain Pod Wiring

| Net | ESP32 Pin | Notes |
|---|---|---|
| I2C SDA | GPIO21 | -> dock pogo pin 3 |
| I2C SCL | GPIO22 | -> dock pogo pin 4 |
| 5V in | VIN | from barrel jack (+) |
| GND | GND | barrel(-), dock pin2, button common |
| BACK | GPIO32 | tactile switch, INPUT_PULLUP, active-LOW |
| SELECT | GPIO33 | tactile switch, INPUT_PULLUP, active-LOW |
| NEXT | GPIO25 | tactile switch, INPUT_PULLUP, active-LOW |
| Buzzer | GPIO26 | optional piezo |
| SDA pull-up | 3V3 -> 4.7k -> SDA | master end only |
| SCL pull-up | 3V3 -> 4.7k -> SCL | master end only |

Pod wire count: **10 wires** (2 barrel, 4 pogo, 3 buttons+GND, 1 buzzer)

No level shifter needed: ESP32 3.3V open-drain I2C works with 5V ATmega (reads >2.0V as HIGH).

## Power Budget
```
Per cell:  motor 240mA + ATmega 20mA + hall 5mA = ~265mA
5 cells:   1.325A
ESP32:     ~80mA
Total:     ~1.4A    5V/3A adapter = 2x headroom
```

## Mechanical assembly status - HOLD

### Cell

The cell cannot be assembled as a final product from the current source:

- the cam socket is only 3.5mm deep for the measured 7.5mm shaft;
- the cam/linkage/spring motion and torque have not passed the real bench test;
- the cell pogo windows have no measured carrier or retention geometry;
- the ULN2003 has no positive board retainer in its pocket;
- insert, motor-pilot, Hall, magnet, and standoff fits are coupon-gated.

For now, keep electronics on the breadboard and print only the checked coupons/fixture. Never trim
the shaft. The resin design integrates each 1.5mm dome into its linkage; there are no bearing balls.
The 2mm OD spring twists over the dome, seats on the linkage flange, and enters the resin dot-insert
counterbore; it is not dropped or glued into the PETG top plate.

### Pod

The pod shell also remains on HOLD. Standard 1x15 female headers have downward solder tails, but the
current shell provides only 1mm-deep blind body channels and no tail/wire exits. The dock pad recess
also has no measured pad retainer or lead route. Do not print the full pod until the exact headers
and dock contacts are selected and those paths are designed/tested.

The owned inline power pigtail is the current connector choice: its body remains outside, only the
two insulated leads pass through the coupon-selected lid slot, and the cable ties to the internal
post before termination. The red lead was measured centre-positive on 2026-08-01.
## Quick Reference
```
POGO:     1=5V  2=GND  3=SDA  4=SCL
CELL J1:  Red=5V  Black=GND  Blue=SDA  Yellow=SCL
CELL J2:  White 5-pin JST (plug in)
CELL J3:  Red=VCC  Black=GND  Green=SIG
BUTTONS:  GPIO32=BACK  GPIO33=SELECT  GPIO25=NEXT
I2C:      GPIO21=SDA  GPIO22=SCL  (4.7k to 3V3)
ADDRESSES: 0x20..0x27 (solder jumpers PB0-PB2)
BOLT:     M2.5x25 x4 per cell (top->standoff->base->boss)
```

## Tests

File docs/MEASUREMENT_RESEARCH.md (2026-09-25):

# Component measurement research

**Updated:** 2026-07-31
**Purpose:** prefill catalogue-standard dimensions before asking for physical measurements.

## Evidence labels

- **MEASURED** — reported from the owned part by AJ.
- **PHOTO-ID** — form factor confirmed from AJ's owned-part photograph.
- **DERIVED** — calculated from reported measurements.
- **SPEC** — published nominal for the identified component family.
- **LIKELY** — strong description match, but the exact clone is not identified.
- **VERIFY** — still needs the owned part, a purchase link, or an exact model number.

The 28BYJ-48 and generic ESP32/ULN2003 boards are made by many factories. A catalogue value is
good evidence for clearance and identification, but not a substitute for a physical reading where
the CAD depends on a press fit or exact header alignment.

## Researched values

| ID | Value to use | Evidence | Decision |
|---|---:|---|---|
| M1 | 28.1 mm | **MEASURED**; 28 mm typical | Use 28.1 |
| M2 | 19.0 mm | **MEASURED**; 19–20 mm variants published | Use 19.0 |
| M3 | 7.5 mm | **MEASURED**; approximately 8 mm typical | Use 7.5 |
| M4 | 5.0 mm | **MEASURED + SPEC** | Use 5.0 |
| M5 | 3.0 mm | **MEASURED + SPEC** | Use 3.0; current 3.2 mm cam bore gives 0.2 mm total clearance |
| M6 | 9.5 mm from mounting face to tip | **MEASURED**; approximately 10 mm typical | Use 9.5 |
| M7a | approximately 9.0 mm | **SPEC** from common dimensional drawings | Verify only if the collar binds |
| M7b | 2.0 mm | **DERIVED**: 9.5 face-to-tip minus 7.5 collar-top-to-tip | Use 2.0 |
| M8 | 34.7 mm | **MEASURED**; 35 mm typical | Use 34.7 |
| M9 | 4.0 mm | **MEASURED**; published variants are about 3.5–4.2 mm | Use 4.0 |
| M10a | approximately 7.0 mm | **SPEC** from common dimensional drawings | Clearance value, not a press fit |
| M10b | approximately 0.8 mm | **SPEC** from common dimensional drawings | Clearance value, not a press fit |
| M11a | 4.1 mm nominal, 4.2 mm max | **SPEC**, 49E/SS49E TO-92S family | Design to max envelope |
| M11b | 1.6 mm | **MEASURED**; 1.6 mm nominal / 1.68 mm family max | Current 1.6 mm pocket is exact-fit; dry-fit because there is no print margin |
| M11c | 3.1–3.2 mm | **SPEC**, 49E/SS49E TO-92S family | Design to 3.3 mm envelope |
| M11d | 1.27–1.30 mm straight-lead pitch | **SPEC**; formed-lead SS49E-F is 2.54 mm | Verify sensor marking/lead form before desoldering |
| M12–M14 | Body dimensions not needed; cable-slot fit remains | **PHOTO-ID** inline female DC pigtail jack | Current pod choice: body outside, cable through coupon-selected slot, internal tie-post strain relief |
| M15 | likely 5.5 mm barrel / 2.1 mm centre pin | **PHOTO-ID + PROJECT SPEC** | Confirm by mating plug or purchase record; photo alone cannot distinguish 2.1 from 2.5 mm |
| M16 | No thread or ring nut | **PHOTO-ID** | Cannot clamp directly into a lid hole |
| M17 | Centre pin maps to red / positive | **MEASURED 2026-08-01** | Verified for the owned pigtail; re-test only if the connector is replaced |
| M18 | 15 pins per row / 30 total | **MEASURED** | Resolved |
| M19 | approximately 51.5–52.0 mm | **LIKELY**, matching 30-pin USB-C CH340C listings | Safe for pod length envelope |
| M20 | approximately 28.0–28.5 mm | **LIKELY**, matching board listings | Safe for pod width envelope |
| M21 | 25.6 mm | **MEASURED** on the owned 30-pin USB-C board | Use 25.6 for printed header channels |
| M22a | approximately 8.3 mm interface; approximately 9 mm shell | **SPEC/LIKELY**, USB Type-C interface and common receptacle | 14 mm opening clears it |
| M22b | approximately 2.5 mm interface; approximately 3.2 mm shell | **SPEC/LIKELY** | 9 mm opening clears it |
| M22c | approximately 3.2 mm above PCB | **LIKELY**, common on-board receptacle | Existing service opening has generous margin |
| M23 | No measurement needed unless cable overmould exceeds 14×9 mm | CAD service envelope | Closed provisionally |
| M24 | approximately 35×32 mm | **LIKELY**, common blue four-LED ULN2003 module | Variants such as 40×21 mm exist |
| M25 | approximately 10 mm bare module; approximately 12 mm with cable bent flat | **SPEC + project fit estimate** | Verify after final solder/cable dressing |
| M26 | JST-XH motor connector/mated plug, approximately 10–12 mm installed | **SPEC/LIKELY** | Same assembly check as M25 |
| M27 | 8×1 mm | **MEASURED/OWNED**, already recorded in live CAD and BOM | Resolved |
| M28 | 6×6×5 mm | **PURCHASE SPEC**, already recorded in BOM and live CAD | Resolved |

## What the online pass proves

1. The red `2601213328` on the motor is a production/traceability code, not a separate motor
   model. The printed model is still **28BYJ-48, 5 V**.
2. The user-reported motor values agree with the common 28BYJ-48 envelope closely enough to use
   for non-press-fit clearances.
3. The blue `MH-Sensor-Series` board is in the KY-024 family and normally uses a 49E linear Hall
   sensor. The bare sensor package is documented; the complete module still cannot fit in the
   base plate.
4. A 30-pin ESP32 designation did **not** prove M21, but the owned board is now measured at
   **25.6 mm**. The live socket-channel pitch now uses that reading.
5. The 2026-07-31 photo confirms an inline female DC pigtail jack with red/black wires. The current
   lid intentionally keeps its connector body outside, passes only the cable pair through a rounded
   slot, and transfers pull load to an internal tie post. A panel-mount jack is not required for
   this revision; the remaining evidence is the physical 5x3 / 6x4 / 7x5 cable-slot coupon.

## Recommended power-connector decision

Use the owned **inline female pigtail** for the current pod. Keep the barrel body outside, pass only
the two insulated leads through the lid, and secure them to the internal tie post before soldering.
Print `pigtail_slot_coupon.gcode` and choose the smallest slot that passes both leads without
scraping or pinching insulation. The middle 6 x 4 mm slot is the current CAD nominal. A threaded
panel jack is only a future redesign option, not a current purchase requirement.

## Sources

- 28BYJ-48 compiled mechanical datasheet and variant warning:
  https://www.gentiam.com/wp-content/uploads/2022/09/GentiamElectronics-28BYJ-48-Stepper-Motor-Datasheet-Rev20220925-final.pdf
- 28BYJ-48 measured dimensional drawing and lot-code explanation:
  https://cookierobotics.com/042/
- Honeywell SS49E product sheet and package drawing:
  https://prod-edam.honeywell.com/content/dam/honeywell-edam/sps/siot/en-us/products/sensors/magnetic-sensors/linear-and-angle-sensor-ics/common/documents/sps-siot-ss3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
- Diodes Incorporated AH49E package limits:
  https://www.digikey.in/en/htmldatasheets/production/1364519/0/0/1/ah49e.html
- Joy-IT KY-024 identification (49E + LM393) and module envelope:
  https://www.joy-it.net/en/products/SEN-KY024LM
- Typical inline adapter dimensions (36.7×14×12 mm):
  https://www.taydaelectronics.com/dc-power-female-plug-5-5-x-2-1mm.html
- Adafruit caliper reading for the same adapter family (37.29×14.2 mm):
  https://forums.adafruit.com/viewtopic.php?t=201119
- Pololu adapter polarity mapping:
  https://www.pololu.com/product/2449
- USB-IF Type-C connector interface dimensions:
  https://www.usb.org/sites/default/files/D1T1-2%20-%20USB%20Type-C%20System%20Overview.pdf
- Matching 30-pin USB-C CH340C ESP32 listing (51.5×28.5 mm):
  https://www.mercadolibre.com.mx/esp32-devkit-v1-wifi-bluetooth-ch340c-usb-tipo-c-30-pines/up/MLMU3429721061
- 30-pin ESP carrier row-spacing variants (0.9/1.0/1.1 inch):
  https://osoyoo.com/it/2025/02/07/osoyoo-breakout-board-for-30p-esp32-esp8266/
- Common blue ULN2003 module dimensions (35×32 mm):
  https://www.tinytronics.nl/en/mechanics-and-actuators/motor-controllers-and-drivers/stepper-motor-controllers-and-drivers/uln2003-stepper-motor-driver-module
- ULN2003 kit module envelope (35×32×10 mm):
  https://d3mk240zzrnosz.cloudfront.net/assets/XC4458_datasheetMain_67866.pdf
- JST XH connector mechanical drawing:
  https://www.jst.com/wp-content/uploads/2025/06/eXH.pdf
- 6×6×5 mm tactile-switch specification:
  https://www.handsontec.com/dataspecs/switches/Tact%20Switch%206x6.pdf

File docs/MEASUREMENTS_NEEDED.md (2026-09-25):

# What I need you to measure

**Updated 2026-07-31. For Mridul.**

This began as a blank measurement list. It now combines your readings with datasheet values and published component envelopes. Values marked **VERIFY** are the only ones that still need the owned part.

An online/specification pass has now prefilled most of the original list. The evidence and source
links are in [`MEASUREMENT_RESEARCH.md`](MEASUREMENT_RESEARCH.md). Do not re-measure catalogue
dimensions unless the item is marked **VERIFY** below.

**M5, M11b, and M21 are now measured.** No additional immediate caliper reading is required.
The remaining power-fit check is selecting the smallest cable-only slot using the pigtail coupon.
M25 is checked later after the driver wires are installed.

**Motor identification:** `28BYJ-48`, 5 V. The red `2601213328` marking is a production/traceability code, not a different motor model.

Each one is written twice:

> 🟢 **In plain words** — what to actually do, no jargon
> 🔧 **Technical name** — the proper term, so you recognise it in datasheets, shops and my messages

The prefilled answer sheet at the bottom shows what is known, where it came from, and what remains.

---

# PART 0 — Words you'll keep seeing

Learn these six and everything below reads easily.

| Word | What it actually means |
|---|---|
| **Diameter** | The width straight across a circle, through the middle. Not around it. |
| **Bore** | A hole. "Bore diameter" = how wide the hole is. |
| **Pitch** | The gap from the centre of one thing to the centre of the next — holes, pins, teeth. Centre-to-centre, **never** edge-to-edge. |
| **Boss** | A raised bump or collar sticking out of a surface. |
| **Ear / lug / tab** | A flat sticking-out tab with a screw hole in it. |
| **Flat-to-flat** | The width across the two flat sides of a rod that isn't fully round. |

**Rule of thumb:** anything called "diameter" or "width" is measured with the **big jaws**.
Anything called "bore" or "hole" is measured with the **small pointy jaws** on top.

---

# PART 0.5 — Using the calipers (30 seconds)

```
        ┌── BIG jaws: measure the OUTSIDE of things
        ▼
   ═══╗ ╔═══════════════════════════════
      ║ ║   [ 12.47 ]  ← screen
   ═══╝ ╚═══════════════════════════════
        ▲
        └── small pointy jaws on TOP: measure the INSIDE of holes
```

- **mm/inch button** — make sure it says **mm**. If a big object reads 0.5 or 1.3, you're in inches.
- **ZERO button** — close the jaws fully, press ZERO, *every session*. Otherwise every reading is
  off by the same amount.
- **Close the jaws gently.** Plastic squashes and you'll read too small. Stop when it stops sliding.
- **Write 2 decimal places.** "12" is useless. "12.47" is what I need.

---

# PART 1 — THE MOTOR ⭐ MOST IMPORTANT

The silver can with the blue plastic base and 5 coloured wires.

**Why this one matters most:** the motor's height sets how high the base plate sits → which sets
how high the cam sits → which sets how long the linkages are. Get the height wrong by 2mm and
**all six braille dots stick up permanently** — every dot reads as "on" and the display is useless.

The CAD says 19mm tall. Nobody has ever checked.

```
                    shaft (the thin metal rod that spins)
                         │
                    ┌────┴────┐
              ┌─────┤  boss   ├─────┐   ← boss = raised collar round the shaft
   ear ───►  ╱      └─────────┘      ╲
            ○                         ○  ◄─── ear = flat tab with a hole
            ╲                         ╱
             └───────────────────────┘  ◄─── THIS flat face is the "mounting face"
             ╔═══════════════════════╗   ▲
             ║                       ║   │ can height
             ║      silver can       ║   │
             ║                       ║   ▼
             ╚═══════════════════════╝
```

### M1
> 🟢 **How wide is the round silver part?** Measure straight across it at its fattest point.
> 🔧 **Can outer diameter** *(guessed: 28mm)*

### M2 ⭐⭐ THE CRITICAL ONE
> 🟢 **How tall is the motor, from the table up to the flat face where the two tabs are?**
> Stand it silver-can-down on a table. Measure up to that flat face — **not** to the top of the
> spinning rod. Just the body.
> 🔧 **Can height, base to mounting face** *(guessed: 19mm)*

### M3
> 🟢 **The spinning rod is NOT in the middle of the can. How far off-centre is it?**
> Look down from above. Measure from the middle of the rod to the middle of the round can.
> 🔧 **Shaft-to-body-centre offset** *(guessed: 8mm)*
>
> *Too fiddly? Instead measure rod-centre to the left edge of the can, and rod-centre to the
> right edge. Give me both and I'll work it out.*

### M4
> 🟢 **How thick is the spinning rod at its widest?** It's not perfectly round — it has two flat
> sides shaved off. Measure the **round** way, the fat direction.
> 🔧 **Shaft diameter** *(guessed: 5.0mm)*

### M5
> 🟢 **Now measure the rod the narrow way — across the two flat sides.** Smaller number.
> 🔧 **Shaft flat-to-flat / across-flats:** **3.0mm measured**
>
> *That shape is called a **double-D**. It's what stops the cam spinning loose on the rod. Both
> M4 and M5 must be right or the cam either won't go on, or will wobble.*

### M6
> 🟢 **How far does the rod stick up above that flat face?** From the flat face (same one as M2)
> to the very tip.
> 🔧 **Shaft length above the mounting face** *(guessed: 10mm)*

### M7
> 🟢 **Is there a small raised ring where the rod comes out of the body? How wide and how tall?**
> **If there's no raised ring, just write "none".**
> 🔧 **Shaft boss diameter and height** *(guessed: 9mm wide; height never guessed at all)*

### M8
> 🟢 **How far apart are the two screw holes in the tabs?** Measure from the middle of one hole
> to the middle of the other.
> 🔧 **Mounting-hole pitch (centre-to-centre)** *(guessed: 35mm)*
>
> *Middle-to-middle is awkward. Easier: measure from the **far outer edge** of one hole to the
> **far outer edge** of the other, tell me that, and I'll subtract the hole width.*

### M9
> 🟢 **How wide is one of those screw holes?** Use the small pointy jaws inside it.
> 🔧 **Mounting-hole bore diameter** *(guessed: 4.2mm)*

### M10
> 🟢 **How wide is the flat tab, and how thick is the metal?**
> 🔧 **Mounting ear width and thickness** *(never measured)*

---

# PART 2 — THE POSITION SENSOR

The small **blue board** with a tiny black 3-legged part on one edge, a blue adjustment screw,
and pins marked AO DO GND VCC.

### ⚠️ Bad news first

**The blue board will not fit inside the machine.** It's roughly 15×11mm plus tall pins. The space
inside the base plate is 5mm thick. There's no version where the whole board fits.

**What has to happen:** the little black 3-legged part on the edge *is* the actual sensor —
everything else on that board is supporting circuitry. You'll need to **unsolder that black part**
and mount just it, running three wires back.

Three solder joints. Fiddly, but genuinely the only option: it has to sit within a couple of
millimetres of a magnet on the spinning disc, and the motor body fills everything else nearby.

**You do NOT need to do this for the demo.** On a breadboard the blue board works fine as-is.

### M11 — the black 3-legged part

You can measure it while it's still soldered on.

```
        ┌─────────┐   ▲
        │  flat   │   │ HEIGHT (M11c)
        │  face   │   │
        └─┬──┬──┬─┘   ▼
          │  │  │     ← 3 legs
        ◄─────────►
          WIDTH (M11a)

     from the side:  ◄─►  THICKNESS (M11b)
```

> 🟢 **M11a — How wide is the black part across its flat face?**
> 🔧 Sensor body width *(guessed: 4.1mm)*

> 🟢 **M11b — How thick is it front-to-back?** **1.6mm measured.** The CAD recess is also
> exactly 1.6mm, so it passes geometrically but has zero print tolerance. Dry-fit and clean or
> lightly sand the pocket before gluing; do not force the sensor.
> 🔧 Sensor body thickness: **1.6mm measured**

> 🟢 **M11c — How tall is just the black block?** Not counting the legs.
> 🔧 Sensor body height *(guessed: 3.1mm)*

> 🟢 **M11d — How far apart are the legs?** Middle of one leg to middle of the next.
> 🔧 Lead pitch *(guessed: 1.27mm)*

---

# PART 3 — THE POWER SOCKET

The 2026-07-31 photo shows a **female inline DC barrel pigtail jack**: the black cylindrical socket
with red and black wires. The adapter's round male plug goes into its front.

This is the selected connector for the current pod revision. Its body remains outside the enclosure;
only the red/black cable pair passes through the lid. The cable must be tied to the internal strain-
relief post before it is soldered, so plug insertion/removal does not load the lid or ESP32.

Print `pigtail_slot_coupon.gcode`, then try the 5x3, 6x4, and 7x5 mm rounded slots in that order.
Use the smallest slot that passes both insulated leads without scraping, pinching, whitening, or
cutting them. The clipped corner marks the 5x3 end; the middle 6x4 slot is the current CAD nominal.
The barrel body itself never passes through the slot.

### ✅ M17 — POLARITY VERIFIED 2026-08-01

The owned pigtail was measured: **red reaches the centre pin and is positive; black is ground**.
Mark the red lead physically and do not reverse it. Repeat the continuity test only if this pigtail
or the adapter is replaced; the circuit has no reverse-polarity protection.

---

# PART 4 — THE ESP32 BOARD

The black board with the silver square shield and USB-C.

### M18 — RESOLVED: 15 pins per side / 30 total

> 🟢 **Count the metal pins along ONE long edge.** Just count them.
> 🔧 Pin count per row

- **15 per side** (30 total) → you have the "30-pin" board
- **19 per side** (38 total) → the "38-pin" board

**Why this matters:** the pod has two printed slots the board's pins drop into. M18 confirms a
30-pin board. M21 is now measured directly from this exact board at **25.6mm**.

> 🟢 **M19 — How long is the board?** The long way.
> 🔧 Board length *(guessed: 51.5mm)*

> 🟢 **M20 — How wide is the board?** The short way.
> 🔧 Board width *(guessed: 28.0mm)*

> 🟢 **M21 — How far apart are the two rows of pins?** Middle of the left row to middle of the
> right row.
> 🔧 Header row pitch: **25.6mm measured; CAD updated**
>
> *Easier: measure from the **outer edge** of the left pins to the **outer edge** of the right
> pins and tell me that instead.*

> 🟢 **M22 — The silver USB socket on the board:** how wide (a), how tall (b), and how far does it
> stand up off the board surface (c)?
> 🔧 USB connector width / height / height above PCB

> 🟢 **M23 — Your USB cable's plug:** not the metal bit — the **plastic body behind it**, the part
> your fingers hold. How wide (a) and how tall (b)?
> 🔧 Connector overmould width and height
>
> *Why: the socket sits ~2mm inside the pod, so the plug body has to pass through the hole in the
> wall too. The old hole was 10×7mm and would probably have blocked your cable. The service
> opening is now fixed at 14×9mm. M23 is optional unless your cable body is larger than that.*

---

# PART 5 — THE MOTOR DRIVER (blue board, 4 red LEDs)

> 🟢 **M24 — How long and how wide is the blue board?**
> 🔧 PCB length × width

> 🟢 **M25 — How tall is it once the wires are soldered flat against it?**
> 🔧 Assembled stack height
>
> *Measure **after** soldering, or press the wires flat and estimate. Do **not** measure it with
> the plug-in jumper wires standing upright — that makes it ~20mm and the space is 16mm. That's
> exactly why the wires must be soldered flat.*

> 🟢 **M26 — Which part on the board stands up tallest, and how tall is it** from the board surface?
> 🔧 Tallest component height

---

# PART 6 — Quick confirmations (10 seconds each)

> 🟢 **M27 — One of your silver disc magnets: how wide and how thick?**
> 🔧 Magnet diameter × thickness *(expect 8mm × 1mm)*

> 🟢 **M28 — One tiny black push-button: how wide is the square body, and how tall is it including
> the round nub on top?**
> 🔧 Tactile switch body and total height *(expect 6 × 6 × 5mm)*

---

## ⚠️ Shopping correction that came out of this work

Your BOM used to say buy a **3mm × 2mm** homing magnet.

### Buy 3mm × 1mm instead.

The disc it glues into is only 2mm thick. A 2mm-deep pocket cut clean through it, punching a
3.2mm hole across three of the six cam tracks — and a linkage foot crossing that hole would drop
in and jam the whole mechanism. A 1mm magnet leaves 0.8mm of material and works just as well,
because it still sits flush against the underside.

Already ordered 3×2mm? They'll be useful elsewhere. Just buy 3×1mm too. ~₹120 for ten.

---

# 📋 CURRENT MEASUREMENT RECORD

This is the consolidated owned-part/specification record. Blank catalogue-only items are no longer
immediate blockers unless a first-print dry-fit shows a conflict.

```
=== MOTOR (owned 28BYJ-48, 5V; red number is a lot/traceability code) ===
M1  can diameter                              = 28.1 mm   [MEASURED]
M2  mounting-face height                     = 19.0 mm   [MEASURED]
M3  shaft offset from can centre             = 7.5 mm    [MEASURED]
M4  shaft diameter                           = 5.0 mm    [MEASURED + SPEC]
M5  shaft across flats                       = 3.0 mm    [MEASURED]
M6  mounting face to shaft tip               = 9.5 mm    [MEASURED]
M7a raised collar diameter                   = ~9.0 mm   [SPEC]
M7b raised collar height                     = 2.0 mm    [DERIVED: 9.5 - 7.5]
M8  mounting-hole pitch                      = 34.7 mm   [MEASURED]
M9  mounting-hole bore                       = 4.0 mm    [MEASURED]
M10a mounting-ear width                      = ~7.0 mm   [SPEC]
M10b mounting-ear metal thickness            = ~0.8 mm   [SPEC]

=== POSITION SENSOR (KY-024 family, bare 49E/SS49E package) ===
M11a body width                              = 4.1 nominal / 4.2 max mm [SPEC]
M11b body thickness                          = 1.6 mm [MEASURED — EXACT-FIT POCKET]
M11c body height                             = 3.1-3.2 mm [SPEC]
M11d straight-lead pitch                     = 1.27-1.30 mm [VERIFY LEAD FORM]

=== POWER SOCKET (photo identified) ===
M12-M14 owned part                           = inline female DC pigtail [CURRENT POD CHOICE]
M15 mating barrel                            = likely 5.5 OD / 2.1 centre mm [CONFIRM WITH PLUG]
M16 panel thread + ring nut                  = NO [PHOTO CONFIRMED]
M17 polarity                                 = red -> centre pin / +5V [MEASURED 2026-08-01]

=== ESP32 BOARD (USB-C, CH340C-family, 15 pins per row) ===
M18 pin count                                = 15 per row / 30 total [MEASURED]
M19 board length                             = likely 51.5-52.0 mm [MATCHING LISTINGS]
M20 board width                              = likely 28.0-28.5 mm [MATCHING LISTINGS]
M21 header-row centre spacing                = 25.6 mm [MEASURED — CAD UPDATED]
M22 USB-C interface / shell                  = ~8.3x2.5 / ~9x3.2 mm [SPEC/LIKELY]
M23 cable body                               = NOT NEEDED unless larger than 14x9 mm

=== MOTOR DRIVER (common blue four-LED ULN2003 board) ===
M24 PCB size                                 = likely 35x32 mm [COMMON VARIANT]
M25 installed height, cable bent flat        = likely ~12 mm [VERIFY AFTER WIRING]
M26 tallest item                             = JST-XH motor plug, ~10-12 mm installed [LIKELY]

=== QUICK CONFIRMATIONS ===
M27 docking magnets                          = 8x1 mm [OWNED / ALREADY IN CAD]
M28 tactile switches                         = 6x6x5 mm [PURCHASE SPEC / ALREADY IN CAD]
```

---

## What happens when you send these back

I re-derive the **whole vertical stack in one pass** — motor height → base plate → cam → linkage
length — rather than patching one number at a time. That's deliberate: these all depend on each
other, so fixing them individually just moves the error somewhere else.

**The remaining hardware decisions/checks are:**

| Waiting on | Why online data is not enough |
|---|---|
| Hall pocket dry-fit | M11b is 1.6mm and the recess is exactly 1.6mm, so real printed tolerance must be checked before gluing. |
| Pigtail cable-slot coupon | Select the smallest 5x3 / 6x4 / 7x5 opening that passes both insulated leads without damage; feed the result into `power_cable_slot_w/h`. |
| M25 later | Final height depends on how the motor cable and soldered wires are dressed during assembly. |

Everything else is now measured, derived, standardized, safely enveloped, or non-critical.

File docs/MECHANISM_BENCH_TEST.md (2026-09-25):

# Braillix mechanism bench test

## Purpose

This fixture tests the real cam facets, 1.6 mm tracks, 1.4 mm linkage foot, resin dot holes,
2 mm return spring, and linkage geometry without depending on the invalid motor socket or the
pending enclosure-height decision.

A generic inclined strip is not an adequate substitute: it would miss radial clearance, adjacent
track edges, phase alignment, real STL faceting, linkage pitching, and dot-hole binding.

## Required parts

- PETG: `printing/gcode_kobra_neo_checked/cam_linkage_test_fixture.gcode`
- tough/ABS-like resin: `cad/stl/cam_linkage_test_resin_set.stl`
- one real spring: OD 2.0 mm, ID about 1.4 mm, 0.3 mm wire, about 4 mm free length
- digital caliper or depth gauge
- thin thread and a small spring scale for the torque check

The resin set has four components: current full cam, dot-5 linkage, dot-6 linkage, and dot insert.
The current cam is test-only. Its motor socket is still invalid.

## Fixture datums

- cam OD: 44.4 mm
- locating well: 45.0 mm diameter, 0.3 mm deep
- hub clearance: 12 mm through-hole
- cam underside seating plane to holder underside: 11.0 mm
- flat cam surface to holder underside: 9.0 mm
- insert body opening: 11.2 x 11.2 mm
- insert flange rebate: 15.2 x 15.2 x 1.2 mm
- holder locating pegs: 3.0 mm into 3.4 mm holes

## Assembly

1. Print the two-piece PETG fixture with its checked G-code.
2. Put the base on a flat table.
3. Place the resin cam tracks upward, with its hub hanging through the 12 mm center hole.
4. Dry-fit the resin insert into the removable X-frame. Do not glue it.
5. Install only one linkage and one spring at a time.
6. Lower the X-frame over all four pegs until it sits on the wide post shoulders.
7. Hold the frame down by hand during testing if the loose locating fit allows lift.

Start with dot 5:

- dot 5 drives track 0 at 12.8 mm radius;
- its foot sits at 0 degrees;
- it is the worst inner-track pressure-angle case.

Then repeat with dot 6:

- dot 6 drives track 5 at 21.3 mm radius;
- its foot sits at 300 degrees;
- it is the longest arm and fastest-changing outer track.

## Test A - dry travel without spring

Rotate the cam slowly through several low-to-high and high-to-low transitions in both directions.

Pass only if:

- the dome moves through the insert hole without visible lateral scraping;
- the linkage does not pitch or wedge;
- the 1.4 mm foot stays within its 1.6 mm track;
- the foot never catches an adjacent track edge;
- the dome needs no finger assistance.

Any skate, snap, jam, or direction-dependent position rejects the current cam/linkage geometry.

## Test B - measured dot height

Reference the caliper/depth gauge to the insert top.

Current source acceptance:

- down: dome top flush within +/-0.10 mm;
- up: 0.80 +/-0.10 mm above the surface;
- readings must agree in both rotation directions.

Reject if the down dot is more than 0.1 mm proud, up travel is below 0.4 mm, or backlash changes the
reading based on rotation direction.

## Test C - real spring return

Twist the actual spring over the 1.5 mm dome and into the 2.2 mm insert bore.

Cycle each linkage 50 times in each rotation direction.

Pass only if:

- the dot returns fully and immediately every time;
- the spring retains visible coil clearance at full lift;
- the 2.2 mm flange does not hit the insert underside;
- the spring never slips past the flange;
- no crack, whitening, scoring, resin dust, or permanent spring deformation appears;
- force does not noticeably increase over the cycles.

The nominal flange-to-insert clearance at full lift is only 0.2 mm. Any contact rejects the design.

## Test D - ramp and dwell

For dot 5, reject any visible side loading, skate, or snap while climbing the inner-track ramp.

For dot 6, stop at the center of high and low dwells and gently rock the cam. Reject if the dot
immediately becomes half-raised or changes height with tiny angular movement. The current outer
flat is only about 1.046 mm against a 1.0 mm tangential foot, leaving about 0.023 mm per side.

## Test E - torque reserve

Wrap thin thread around the cam rim. Pull tangentially with a spring scale while the linkage crosses
a ramp.

Compute:

`test torque = pull force x 0.0222 m`

Measure dot 5 and dot 6 separately. Later sum the measured transition torques for all dots that
change at the same state boundary; transition 31 to 32 flips all six.

Final requirement:

`worst simultaneous-transition torque < 50% of measured motor stall/holding torque`

The 2x reserve covers gearbox loss, backlash, resin variation, dust, and ageing. "It moves by hand"
is not enough.

## Release decision

The mechanism remains HOLD unless both dot-5 and dot-6 tests pass:

- dry travel;
- measured height;
- 50 spring cycles in both directions;
- stable high/low dwell;
- no damage or scoring;
- at least 2x motor torque reserve.

An FDM version may expose a failure, but an FDM pass does not validate the intended resin friction
pair or 1.7 mm resin dot holes.

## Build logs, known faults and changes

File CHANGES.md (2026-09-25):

# Braillix CAD — Change Log & Engineering Report
**Date:** 2026-05-02  
**Session authors:** Mridul (hardware lead), Atishay (hardware engineer)  
**AI-assisted review & implementation**

---

## v7.9 — 2026-07-31 (owned-part measurements resolved)

- Recorded M5 = 3.0mm, M11b = 1.6mm, and M21 = 25.6mm as owned-part measurements.
- Updated the ESP32 socket-channel pitch from the 25.4mm placeholder to the measured 25.6mm.
- Confirmed the existing 3.2mm cam bore provides 0.2mm total clearance across the measured shaft flats.
- Kept the Hall recess at 1.6mm; it is an exact geometric fit with zero print margin and requires a dry-fit.
- Photo-identified the owned power part as an inline female DC pigtail jack, not a panel-mount part.
  It remains useful for testing; the final pod still needs a selected threaded 5.5×2.1mm jack.

## v7.8 — 2026-07-31 (component measurement research)

- Researched the full M1-M28 list and labelled every value as measured, derived, published spec,
  likely clone match, or still requiring the owned part.
- Prefilled the measurement handout and added `docs/MEASUREMENT_RESEARCH.md` with source links.
- Corrected ESP32 and barrel-jack M-number comments in the live parameter file; no geometry changed.
- Identified that the owned yellow/black power adapter is inline, while the CAD assumes a
  panel-mount jack; final hardware should standardize on a specified panel-mount part.

## v7.7 — 2026-07-31 (USB-C recovery access)

- Widened the ESP32 pod USB-C service opening from **13 × 9 mm** to **14 × 9 mm**.
- Preserved the existing 9 mm height; the proposed 7 mm height would have reduced cable-overmould clearance.
- Regenerated the pod STL, all six PETG G-code files, and the measurement PDF.
- OpenSCAD verification: simple geometry, expected connected-volume count, and exactly 36 mm³ removed.
- Corrected Orca CLI's selected build-plate temperature from 60°C to 80°C and hardened the slicer guard to validate the actual emitted bed temperature and fail nonzero on unsafe output.
- OrcaSlicer verification: actual heater commands confirmed at 235/80°C first layer and 230°C thereafter.

## v7.3 — 2026-07-29 (pre-assembly audit — 5 blocking CAD defects found)

Full pre-assembly audit ahead of a presentation demo, run as five parallel agents and then
**independently re-verified against source** before being believed. Six new documents.

### Firmware bugs FIXED in breadboard_test.ino
1. **"CW 90 deg" moved 512 steps = 45 deg.** At 4096 steps/rev, 90 deg is 1024. Button label,
   log line and self-tests all claimed 90. Fixed to 1024.
2. **Full-revolution log said "2048 steps" while moving 4096** — 2048 is exactly the full-step
   error this project already corrected once; printing it on the dashboard undid that.
3. **The dashboard froze for the whole ~10s of homing.** `doHoming()` never called
   `server.handleClient()` inside its `while (stepper.run())` loops (unlike `runTests()`, which
   does). The page died at precisely the moment you say "watch it find home." 3 calls added.

### CAD defects found — ALL VERIFIED FROM SOURCE, all block assembly
1. **The hall sensor pocket does not exist.** Its farthest corner is at r=22.31mm and the Ø46
   cam pocket has r=23.00mm, cut over the identical z-range (2..6). It is entirely subsumed —
   the printed part has no hall pocket at all. Separately, the pocket was sized 5.3x4.3x3mm for
   a bare TO-92, but the owned part is a blue MH-Sensor-Series module several times larger.
2. **The motor's right mounting ear has nothing to screw into.** Hole at x=+9.5, y=0 sits inside
   the 22x16mm spring-cavity through-window. One-screw motor mount.
3. **Nav buttons cannot actuate.** Shaft 4.5mm minus flange 1.5mm = 3.0mm projecting, against a
   4.0mm pod wall — 1mm short of even reaching through, before the switch gap.
4. **ESP32 DevKit overruns the pod cavity by 1.75mm** (board +29.75 vs cavity +28.00). Also the
   USB cutout is at the wrong height, and devkit_width/hdr_row_pitch describe a 38-pin board
   while every doc says 30-pin.
5. **The cam homing-magnet pocket craters the running surface.** Ø3.0 at r=17.35 spans
   r 15.85..18.85 and overlaps **tracks 2, 3 AND 4** — the 1mm linkage foot rides over that hole
   once per revolution. (The audit reported two tracks; re-verification found three.)

Also found: the cam bore is a through-hole giving 6mm engagement, not the 8mm its comment
claims, and the hub lands 2mm proud; the barrel-jack cradle collides with the cavity wall so
the lid cannot close; base-plate standoffs overhang the plate edge by 1mm.

**None of these block the presentation demo**, which runs on a breadboard and needs no printed
parts. They all block physical assembly.

### Print troubleshooting — previous advice was wrong
The old guidance to print `outer_box` rim-down was incorrect and probably CAUSED the
unremovable supports: nothing bridges a 60mm cavity, and it hangs the four Ø7.8x37mm bosses
tip-first in air. Root cause of welded supports is `Support Placement = Everywhere` plus
Cura's PLA-tuned Z distance; PETG needs ~0.4mm Top Distance and `Support Distance Priority =
Z overrides X/Y`. The real fix is that **no PETG part needs supports at all** — every overhang
is already handled in CAD (teardrop pockets, 0.6mm printed bridges, boss gussets).

### New documents (all with PDFs)
`MASTER_BOM.md` · `ASSEMBLY_BIBLE.md` · `CAD_FIT_CHECK.md` · `DEMO_SCRIPT.md` ·
`PRINT_TROUBLESHOOTING.md` · `BRAILLE_READABILITY.md` · plus `docs/md2pdf.py` (reusable
markdown->PDF converter). `SHOPPING_LIST.md` stamped SUPERSEDED — it still listed 4mm pen
springs and 2mm bearing balls, both wrong since v7.1.

### Braille standards check
Dot diameter 1.5mm is **in spec** (1.44-1.60). Dot height 0.8mm is 1.6x too tall. Vertical
spacing 2.6mm is fine; horizontal 4.8mm is 1.9x too wide — and the reason for that (2.5mm holes
merging) disappeared in v7.1 when holes shrank to 1.7mm. Nobody revisited it. Worth ~4h after
the demo to make the cell genuinely standard-compliant within the character.

## v7.2 — 2026-07-29 (top plate leaves the resin batch; dot-flush bug fixed)

**Resin cost cut ~4.5x.** The 68x70mm top plate was 19.85 of the 23.8 cm3 resin
bill, but almost all of it is plain flat structure an FDM printer handles fine.
Only two features genuinely need resin: the six 1.7mm dot holes (the dome has to
SLIDE through them, and a 0.4mm nozzle prints them ~1.4mm and furry) and the six
2.2mm spring bores, whose 0.4mm dividing walls are one nozzle width on FDM.

Those moved into **`dot_insert.scad`** — a 15x15x3.2mm resin tile, **0.45 cm3** —
which glues into a pocket in the now-PETG top plate.

```
              RESIN                    PETG
  before   19.85 cm3  (incl. plate)      -
  after     4.38 cm3  (incl. insert)   15.46 cm3  (print it yourself)
```

- **`dot_insert.scad` (NEW)** — top-hat form: an 11mm body drops through the plate,
  a 15mm flange lands on a rebate whose floor is the **glue shelf** (2mm wide all
  round, ~106mm2 of contact). Top chamfered so a reading finger doesn't catch the
  seam. Verified surfaces at 0.0 / 2.0 / 3.2mm.
- **`top_plate.scad`** — dot holes and spring bores removed; now carries only an
  11.2mm opening + 15.2mm rebate. Fully FDM-friendly.

**BUG FIXED — every dot was permanently raised.** `link_total_h` measured to the
plate's outer top (58.0), but the plate has a 0.8mm finger-pad recess over the
middle, so the surface the dots actually emerge through is at 57.2. Every dot
therefore stood 0.8mm proud when DOWN and 1.6mm when UP — all six always readable,
which is not braille. `link_total_h` 13.0 -> 12.2mm. Now flush at rest, 0.8mm proud
when lifted (verified: 0.00mm error).

- **Linkages: 12 (two full sets).** All eight were only 4% of the plate — the cam
  disc is 94% of it — so a second full set costs ~4% and covers a snapped part or a
  second cell. Laid out 3 columns x 4 rows.
- **Count-dots moved to the arm UNDERSIDE and shrunk** (0.9 -> 0.6mm dia, 0.5 ->
  0.35mm proud): invisible in normal view, still countable by fingernail. They earn
  their place because arms differ by as little as 0.67mm and fitting the wrong one
  puts its foot on the wrong cam track. 2.35mm clearance above the cam bump.
- Removed superseded v7.0 files `print_resin_cam_linkage` / `print_resin_nav_buttons`.

## v7.1 — 2026-07-26 (return spring moves onto the dot axis)

v7.0 seated the return spring on a 5mm pad **halfway along the arm**. Rejected by Mridul,
and he was right: physically the return force belongs on the dot axis, where the dot is.
v7.1 puts it there and makes it actually fit.

**Why it did not fit before, and what changed.** Braille rows are 2.6mm apart, so a spring
wrapped around one dot must be under ~2.4mm OD or it fouls the springs above and below it.
With the old 2.2mm nub that was impossible at any wire gauge:

```
nub 2.2mm -> spring ID 2.6, OD 3.1  COLLIDES (-0.5mm)
nub 1.8mm -> spring ID 2.2, OD 2.7  COLLIDES (-0.1mm)
nub 1.0mm -> spring ID 1.4, OD 2.0  FITS, 0.6mm to spare
```

So the nub slimmed 2.2 -> 1.0mm and the spring became a **2mm OD micro spring** (a stock
catalogue size, 0.3mm stainless). **Ballpoint-pen springs are ruled out permanently** —
at ~4mm OD they need 4.2mm of pitch and we have 2.6mm.

Side effect worth having: the dot dropped 2.2 -> **1.5mm, which is the real braille
standard** (1.44-1.6mm). The old dome was oversized.

- **`linkage.scad` rev 4.1** — mid-arm pad deleted; **spring flange** (2.2mm) added on the
  upper riser; nub 2.2 -> 1.0mm; dome 2.2 -> 1.5mm; count-dots back on the arm.
- **`top_plate.scad`** — spring counterbores are **coaxial with each dot hole** again (2.2mm
  x 2.5mm deep), dot hole 2.5 -> 1.7mm. Documented honestly: only 0.4mm of plate is left
  between the three bores in a column, which is the unavoidable price of a spring on the
  dot axis at braille pitch.
- **`mech_layout.scad`** — spring/nub/dome/flange dimensions and the vertical placement now
  live here, shared by linkage and plate.
- **`docs/SOURCING.md`** — 2mm micro springs (assortment kit recommended), soft-sponge
  fallback, and bearing balls marked NO LONGER NEEDED (the dot is printed).
- **New print plates** for quoting: `print_resin_1_all` (cam+linkages+plate+buttons),
  `print_resin_2_no_buttons`, `print_resin_3_cam_linkages`.

Assembly: thread each spring over the 1.5mm dome by twisting it on past the 1.4mm bore —
Mridul's own idea, and exactly the right trick for a 0.1mm interference on a steel coil.

Verified: 15/15 numeric checks pass (spring vs row pitch 0.60mm, flange vs neighbour 0.40mm,
flange-to-plate clearance when raised 0.20mm, spring working length 3.5mm down / 2.7mm up
against 1.5mm solid). Flange and dome diameters confirmed by measuring the rendered STL
directly: 2.20mm at Y=8.0 and 1.50mm at the dome, total height 13.00mm.

## v7.0 — 2026-07-26 (spread feet — the mechanism becomes buildable)

The v6.x mechanism could not be assembled. Two independent checks proved it:
six arms all ran from the braille cluster to the SAME radial line, so 14 pairs
overlapped in plan view and each needed its own height — six stacked levels
need ~11.5mm and only 6.5mm exists between the cam surface and the top plate.
Three arms sat inside the top plate. Separately, the dot never emerged: the
linkage was 1mm too short, so it topped out 0.2mm BELOW the reading surface.

**Fix: spread the six feet 60° apart around the disc**, and give each braille
dot the foot that points the way that dot already sits. The arms then fan
outward and never cross (closest pair 2.60mm vs 1.0mm needed), so **all six
share one arm height** and the crowding problem disappears instead of being
fought. Device size, cam diameter and print cost are all unchanged.

- **`mech_layout.scad` (NEW)** — single source of truth for everything the cam,
  linkages and top plate must agree on (track radii, dot positions, the
  dot→track/angle assignment, the vertical stack, spring seats). Created
  specifically to stop the stale-duplicate-number bugs that produced v6.x.
- **`braille_cam.scad`** — per-track phase: each track's bump pattern is carved
  pre-rotated by its own foot's angle, so all six feet still read the same state.
  One line. Without it each foot reads a different letter.
- **`linkage.scad` rev 4.0** — `arm_y` is now ONE constant (was six heights);
  `total_h` 12→13 so the dot actually reaches the surface; foot rebuilt as a
  proper 0.5mm roll (was a teardrop wedge tapering to a 0.2mm point); braille
  dot is a **printed dome** (no glued 2mm ball, no machined cup, nothing to
  source); return-spring pad added on the arm; fillets on every internal corner
  (strength — sharp corners are where resin cracks); count-dots on the pad rim
  so the six parts can be told apart in the hand.
- **`top_plate.scad`** — spring pockets moved OFF the dot axis. At 2.6mm row
  pitch three 4.5mm pockets merged into one slot; there were never six pockets.
  Now over the arm pads, 9.6mm apart.
- **Software** — `DOT_TO_BIT` lookup replaces the old formula; authority is
  `dot_track` in `mech_layout.scad`.

Verified: closest arms 2.60mm (need 1.0), spring seats 9.58mm apart (need 5.4),
arm-to-plate clearance 3.70mm, dot proud 0.80mm, foot clearance inside its own
track 0.10mm. Arms also got SHORTER (10.4–17.9mm, was 15.4–19.1mm) = stiffer.

## v6.2 — 2026-06-13 (over-cap lids + boss reinforcement; built via builder/supervisor agents)

Driven by a 2nd round of fit-test photos. Built by a BUILDER agent and visually verified
by a SUPERVISOR agent (rendered PNGs from multiple angles, checked for floating/colliding
geometry). All parts `Simple: yes`; topology as expected.

- **Top plate + pod lid → OVER-CAP design.** The old inset plate/lid left a visible gap ring
  whenever a PETG print came out slightly small. Both are now caps that cover the full
  footprint with a 1mm overhang + 4mm skirt on the **±Y faces only** (±X stay flush — they're
  docking faces and must mate flat). Mounting/screw holes enlarged for print tolerance
  (top plate screw 2.8→3.2, c-bore 5.0→5.6; pod lid screw 2.4→2.8).
- **Box walls shortened 58→54mm** (`wall_top_h`) so the 4mm over-cap sits on top and total
  height stays 58. `shell_height=58` kept as the reference for all feature positions, so
  nothing else moved.
- **Corner screw bosses reinforced** (they snapped on the real print): added a cone gusset
  flaring from Ø13 at the floor to Ø7.8, fused into the floor + cavity wall, below the
  mid-plate. Pairs with a print-setting fix → **set Wall Loops/perimeters = 5** on the slicer
  so small bosses print solid (perimeters matter more than infill % for these).
- **Pod lid jack cradle** (bare-socket jack has no nut): a box/U-pocket under the jack hole
  takes the plug insertion force. ⚠️ **PLACEHOLDER dims — must measure the real jack.**
- Pod shell: removed the now-redundant inner lid-locating lip (the over-cap skirt locates it).

DEFERRED to next round (awaiting Mridul's measurements): motor redesign (real shaft/body/
mount dims), and finalizing the jack cradle to the real bare-socket dimensions. print_batch/
+ zip NOT rebuilt yet for this reason.

## v6.1 — 2026-06-12 (physical fit-test fixes — Anycubic Kobra Neo, 0.4mm PETG)

Full PETG batch was printed and inspected in hand. See the **v6.1 addendum (§6.5)** in
`.ai-sync/artifacts/cad_audit_v6_2026-06-04.md` for measured FDM limits.

- **Magnet pockets resized for the REAL magnets — 8×1mm discs** (CAD assumed 3×2). Now 2 per
  docking face at y=±14 with **teardrop tops** (round side-wall pockets fused closed on FDM).
  Center magnet dropped (8.4mm pocket would collide with the pogo window).
- **All fine braille removed from PETG parts** — 1.4mm dots printed as mush. Replaced with bold
  shapes: box front chevron groove, 1/2/3 count-grooves under pod nav buttons, 3 bold ridges as
  pod lid ID, 45° diamond orientation ridge (the old one was buried INSIDE the wall — never
  printed). Real braille remains on resin parts only.
- Sacrificial bridges 0.4→0.6mm; pilot holes M2 1.7→2.0 / M2.5 2.1→2.3; end-cap snap lips
  0.5→1.0; switch nibs thickened; antenna slots 2→3mm; lid lip clearance +0.2; hall pocket +0.3.
- **`pogo_end_cap.scad` had broken geometry** (mis-centered interior cube gutted the shell;
  floating end marker) — fixed, now a proper hollow snap cap.
- **Linkages: laser-cut metal → RESIN-printed** (rev 3.1; no laser vendor available). New
  `print_batch/Batch4_Resin/` with cam, top_plate, nav_cap, linkage ×8. Stale reference table
  refreshed for inner_radius=12.
- **ULN2003 prototype fit:** module fits the 16mm cell pocket only with wires soldered flat
  (~12mm vs 20mm with Duponts). Mid-plate gained a relief slot at (+X,−Y). Muscle-board PCB
  fab deferred. Procedure documented in WIRING_AND_ASSEMBLY.md (also fixed stale comb step).
- New `docs/SOURCING.md` (springs + pen-spring fallback, 2mm balls, deferred pogo, fasteners).
- All changed parts render `Simple: yes`; print_batch + workshop zip rebuilt.

## v6.0 — 2026-06-04 (pre-patent polish pass)

See `.ai-sync/artifacts/cad_audit_v6_2026-06-04.md` for the full audit.

- **DELETED `linkage_comb.scad` + `linkage_comb.stl` (SCRAPPED).** The 6 metal linkages are
  constrained at **both ends** — the foot rides its cam track, and the nub is laterally guided by
  the 2.5mm round hole in the top plate — so a separate comb guide is redundant. (It also carried
  a stale `inner_radius=8` that no longer matched the cam/linkage `12.0`.)
- Braille pitch decision: **kept at 4.8mm "jumbo"** (large-format / braille-learner positioning).
- Material split locked: RESIN = cam, top_plate, nav_cap; PETG = box, plates, pod, end-cap.
- Further v6 polish (keying, PETG bridges, wider gutters, pod ⠿ marker, nav braille, hall
  comment, jack guard ring) tracked in the audit artifact.

---

## Overview

All five original OpenSCAD render files were audited before any physical prototyping. Four critical dimensional bugs were found that would have caused assembly failure on the first print. All were fixed. One new file was created (linkage set). A Blender presentation render was set up.

Nothing has been physically printed yet — all fixes are pre-print.

---

## File Status Summary

| File | Status | Nature of change |
|---|---|---|
| `base_plate.scad` | **Modified** | Bug fixes + new Hall sensor pocket |
| `top_plate.scad` | **Redesigned** | Full rewrite — wrong size, wrong holes, wrong slots |
| `braille_cam2.scad` | **Modified** | Added magnet homing pocket |
| `braille_cam.scad` | **Deprecated** | Comment added, file kept as archive |
| `outer box.scad` | **Modified** | Added pogo pin connector slots |
| `linkage.scad` | **NEW** | Created from scratch — 6 laser-cut metal cranks |
| `braillix_assembly.blend` | **NEW** | Blender exploded-view scene |
| `assembly_preview_eevee.png` | **NEW** | EEVEE preview render |

---

## 1. `base_plate.scad` — Bug Fixes + Hall Sensor

### Bug 1 — Cam pocket too small (would have jammed on assembly)

**Original:**
```openscad
cam_pocket_diameter = 35;
```

**Fixed:**
```openscad
cam_pocket_diameter = 37; // 36.4mm cam OD + 0.3mm clearance each side
```

**Why:** The cam disc outer radius is `inner_radius + dots × (track_width + track_gap)` = `8 + 6×(1.6+0.1)` = `18.2mm` → **OD = 36.4mm**. A 35mm pocket is 1.4mm too small. The cam disc cannot be inserted. Fixed to 37mm (0.3mm clearance per side).

---

### Bug 2 — Duplicate `ribs()` call (geometry corruption)

**Original assembly block:**
```openscad
union() {
    difference() { ... }
    standoffs();
    intersection() {
        translate([0,0,-rib_height]) main_body();
        ribs();
    }
    translate([0,0,0]) ribs();  // ← DUPLICATE bare call, unconstrained
}
```

**Fixed:**
```openscad
union() {
    difference() { ... }
    standoffs();
    intersection() {
        translate([0,0,-rib_height]) main_body();
        ribs();
    }
    // Bare ribs() call removed
}
```

**Why:** Calling `ribs()` outside the `intersection()` added floating rib geometry extending beyond the plate boundary. The `intersection()` correctly clips ribs to the plate footprint. The bare call created duplicate overlapping geometry — bad for STL export and slicer.

---

### Addition — Hall effect sensor pocket

**Added parameters:**
```openscad
hall_pocket_x = 19;   // Just outside cam track area (cam radius 18.2mm + 0.8mm)
hall_pocket_y = 0;
hall_pocket_w = 5;    // SS49E / A3144 footprint
hall_pocket_d = 4;
hall_pocket_h = 3;    // Leaves 2mm floor under sensor
hall_wire_w   = 2;    // Wire channel width
hall_wire_d   = 1;    // Wire channel depth
```

**Added module:**
```openscad
module hall_sensor_pocket() {
    // Rectangular recess for Hall effect sensor body
    translate([hall_pocket_x - hall_pocket_w/2,
               hall_pocket_y - hall_pocket_d/2,
               base_thickness - hall_pocket_h])
        cube([hall_pocket_w, hall_pocket_d, hall_pocket_h + 1]);
    // Wire channel running to plate edge
    translate([hall_pocket_x + hall_pocket_w/2,
               hall_pocket_y - hall_wire_w/2,
               base_thickness - hall_wire_d])
        cube([base_length/2 - hall_pocket_x - hall_pocket_w/2 + 1,
              hall_wire_w, hall_wire_d + 1]);
}
```

**Why:** The homing system requires a Hall effect sensor (SS49E or A3144) fixed on the base plate at a known angular reference. The magnet on the cam disc passes over it on every rotation. Without this pocket, the sensor would sit proud of the surface and be crushed by the cam disc. The pocket is at x=19mm — 0.8mm outside the outermost track edge (18.2mm) — so the cam disc clears it.

---

## 2. `top_plate.scad` — Full Redesign

The original file had three independent bugs. Since fixing all three required changing almost every module, the file was fully rewritten as **v2.0**.

### Bug 1 — Plate too small to reach standoffs

**Original:**
```openscad
plate_width = 20;
plate_height = 28;
```
The base plate standoffs are at `±15mm` from centre = 30mm grid. A 20×28mm plate cannot physically reach ±15mm in X.

**Fixed:**
```openscad
plate_size = 34.0;  // Square — reaches standoffs at ±15mm with 2mm margin
```

---

### Bug 2 — Mounting holes in wrong pattern

**Original:** 3 holes at 120° on a 12mm radius circle.  
**Base plate:** 4 standoffs at `[±15, ±15]` (a 30×30mm square grid).

These patterns are geometrically incompatible — none of the 3 holes align with any of the 4 standoffs. The top plate could not be bolted down.

**Fixed:**
```openscad
standoff_offset = 15.0;
screw_dia       = 2.8;    // M2.5 clearance
counterbore_dia = 5.0;    // M2.5 button-head counterbore
counterbore_depth = 1.5;

module mounting_holes() {
    for(x = [-1,1]) for(y = [-1,1]) {
        translate([x * standoff_offset, y * standoff_offset, 0]) {
            translate([0, 0, -1]) cylinder(d=screw_dia, h=plate_thickness + 5);
            translate([0, 0, plate_thickness - counterbore_depth])
                cylinder(d=counterbore_dia, h=counterbore_depth + 1);
        }
    }
}
```

4 corner holes at `[±15, ±15]` exactly match the 4 base plate standoffs.

---

### Bug 3 — Round pin bores instead of rectangular linkage slots

**Original:** `cylinder(d=1.75, ...)` — round 1.75mm diameter bores.

**Problem:** The linkages are flat 1mm thick laser-cut metal pieces. A round bore doesn't constrain the linkage from rotating/twisting. The linkage would spin in the hole rather than translate vertically, jamming the pin. Also 1.75mm is too loose for a 1.0mm thick flat piece.

**Fixed:**
```openscad
slot_width  = 1.2;   // 1mm metal + 0.2mm clearance
slot_length = 3.0;   // Allows linkage travel (lift = 0.8mm, margin = 1.1mm each side)

module linkage_slot() {
    translate([-slot_width/2, -slot_length/2, -1])
        cube([slot_width, slot_length, plate_thickness + 5]);
}
```

1.2×3mm rectangular slots oriented along the Y-axis (linkage travel direction). The slot constrains the linkage so it can only translate up/down — no rotation possible.

---

### Additions in v2.0 (beyond bug fixes)

- **Finger pad recess:** 0.8mm shallow recess on top face for tactile boundary
- **Spring pockets:** 3.5mm dia × 1.5mm deep round pockets on underside for return springs (separate from linkage slots — springs are round, slots are rectangular)
- **Thumb ridge:** Small raised ridge on left edge (`sphere(r=0.6)` hull) so a blind user can orient the cell by touch
- **Slot chamfers:** 0.3mm lead-in chamfer on each slot opening to guide linkage insertion during assembly

---

## 3. `braille_cam2.scad` — Magnet Homing Pocket

### Addition — Magnet pocket on disc underside

**Added parameters:**
```openscad
magnet_dia    = 3.0;   // 3mm dia neodymium disc magnet
magnet_depth  = 2.0;   // 2mm deep (magnet sits flush with disc bottom)
magnet_radius = 17.35; // Centre of outermost track — consistent reference
magnet_angle  = 0;     // Defines angular "home" position
```

**Implementation:** The entire cam assembly is wrapped in a `difference()` that subtracts the magnet pocket from the disc underside:

```openscad
difference() {
    union() {
        // solid floor cylinder
        // central D-shaft hub
        // 6 track polyhedra
        // debug markers (preview_mode only)
    }
    // Homing magnet pocket
    translate([magnet_radius * cos(magnet_angle),
               magnet_radius * sin(magnet_angle),
               -1])
        cylinder(d=magnet_dia + 0.2, h=magnet_depth + 1, $fn=30);
}
```

**Why:** The motor has no encoder. On every boot, the ESP32 must find position 0 before accepting Braille commands. The magnet passes the Hall sensor once per revolution — the firmware reads this as the home pulse and sets its step counter to 0. `magnet_radius = 17.35mm` is the centre of track 5 (outermost), chosen to be inside the disc OD (18.2mm) so nothing protrudes.

### Also fixed — `preview_mode` default

Changed `preview_mode = true` → `preview_mode = false` to prevent debug marker cubes from appearing in STL exports by default.

---

## 4. `braille_cam.scad` — Deprecated

**Added at top of file:**
```openscad
// DEPRECATED — use braille_cam2.scad
// This file uses 1.0mm pin lift and a pre-baked polyhedron mesh (not parametric).
// braille_cam2.scad supersedes this with 0.8mm lift, S-curve ramps, D-shaft hub,
// magnet homing pocket, and full parameter control.
```

File retained as archive. Do not export STLs from this file.

---

## 5. `outer box.scad` — Pogo Pin Connector Slots

### Addition — Inter-cell UART connector slots

**Added parameters:**
```openscad
has_right_pogo  = true;       // Set false for last cell in chain (right wall stays solid)
pogo_slot_w     = 10;         // Wide enough for 4-pin 2mm-pitch PCB connector
pogo_slot_h     = 8;          // Height of rectangular window
pogo_slot_depth = wall_thickness + 2;  // Through-wall cutout
pogo_z          = floor_thickness + (shell_height - floor_thickness) / 2;  // Mid-height
```

**Added module:**
```openscad
module pogo_connector_slots() {
    // Left wall — spring pins face out to contact previous cell
    translate([-shell_length/2, 0, pogo_z])
        cube([pogo_slot_depth, pogo_slot_w, pogo_slot_h], center=true);
    // Right wall — contact pad / PCB receiver side (conditional)
    if(has_right_pogo)
        translate([shell_length/2, 0, pogo_z])
            cube([pogo_slot_depth, pogo_slot_w, pogo_slot_h], center=true);
}
```

**Why:** Braillix cells daisy-chain via 4-pin pogo connectors (5V, GND, TX, RX). The spring pins on the left wall of each cell press against the contact pads on the right wall of the previous cell when cells are docked together. The last cell in a chain has no right neighbour — set `has_right_pogo = false` to keep its right wall solid.

---

## 6. `linkage.scad` — New File (Laser-Cut Metal Cranks)

**Created from scratch.** Not 3D-printed — these are laser-cut from 1mm stainless steel or aluminium sheet.

### Purpose

Each linkage is a stair-step flat metal crank that bridges one concentric cam track to its corresponding Braille pin slot. When the cam rotates to a state where track N is in the "up" position, it pushes linkage N upward, which lifts the corresponding pin through the top plate slot.

### Geometry (per linkage)

```
Foot    → 2.0mm wide × 2.5mm long, rounded tip (rides on cam track surface)
Riser   → 1.0mm wide, 9.0mm tall (clears cam disc height + base plate thickness)
Arm     → horizontal bridge from cam track radius to Braille dot X position
Nub     → 1.2mm wide × 2.0mm long × 1.5mm tall (fits top plate slot exactly)
```

All features extruded to 1.0mm thickness (sheet metal gauge).

### Track-to-dot mapping

| Linkage | Track | Track centre radius | Dot | Dot X | Dot Y |
|---|---|---|---|---|---|
| 0 | 0 (innermost) | 8.85mm | dot 1 | −2.4mm | +2.6mm |
| 1 | 1 | 10.55mm | dot 2 | −2.4mm | 0mm |
| 2 | 2 | 12.25mm | dot 3 | −2.4mm | −2.6mm |
| 3 | 3 | 13.95mm | dot 4 | +2.4mm | +2.6mm |
| 4 | 4 | 15.65mm | dot 5 | +2.4mm | 0mm |
| 5 | 5 (outermost) | 17.35mm | dot 6 | +2.4mm | −2.6mm |

### Key parameters

```openscad
foot_w        = 2.0;   // Foot width
riser_h       = 9.0;   // Riser height — clears cam + base plate surface
nub_w         = 1.2;   // Must match top_plate slot_width exactly
nub_h         = 1.5;   // Protrusion above top plate
track_width   = 1.6;   // Must match braille_cam2.scad
inner_radius  = 8.0;   // Must match braille_cam2.scad
col_spacing   = 4.8;   // Must match top_plate.scad
row_spacing   = 2.6;   // Must match top_plate.scad
```

### Export instructions

In OpenSCAD: **File → Export → Export as DXF**. Send the DXF to any laser cutting service. Material: 1mm stainless steel (recommended) or 1mm aluminium. Post-process: sand the foot tips smooth, lubricate with silicone grease.

---

## 7. Blender Assembly Scene

### File
`renders/braillix_assembly.blend`

### Setup
- **Engine:** Cycles, GPU Compute (CUDA — GTX 1650 compatible, no OptiX needed)
- **Samples:** 256 with OIDN denoiser
- **Resolution:** 1920×1080
- **Output:** `renders/assembly_render.png`

### Objects and materials

| Object | Z position (exploded) | Material |
|---|---|---|
| Outer_Box | 0mm | Dark grey PLA |
| Base_Plate | 86mm | Grey PLA |
| Cam_Disc | 149.5mm | Translucent resin (SLA) |
| Linkage_1–6 | 214.5mm | Brushed steel (metallic) |
| Top_Plate | 275.5mm | White PLA |

### Lighting
4× SUN lights (distance-independent — correct for mm-scale scenes):
- Key light: left-front, 45° elevation, 5W
- Fill light: right, 60° elevation, 2W
- Rim light: rear-right, 30° elevation, 3W
- Top light: directly above, 3W

### How to final render
Open `braillix_assembly.blend` in Blender → click the 3D viewport → press **F12**. Render saves automatically to `renders/assembly_render.png`. Takes ~3–5 minutes on GTX 1650. The last ~2 seconds is OIDN denoising on CPU — normal, not a crash.

---

## 8. `outer box.scad` — Navigation Buttons (2026-05-03)

Three 12×12mm momentary tactile switches added to the front face of the enclosure.

### Button layout

```
Front face (y = −shell_width/2):

 [BACK]        [SELECT]    [NEXT]
  x=−24mm       x=+1mm     x=+24mm
  z=10mm        z=10mm     z=10mm
```

**BACK (left):** display previous character  
**SELECT (centre):** confirm MCQ answer / enter  
**NEXT (right):** display next character

### Parameters added

```openscad
btn_hole_dia    = 12.5;   // 12mm switch body + 0.5mm clearance
btn_z           = 10;     // comfortable thumb height from floor
btn_x_back      = -24;    // LEFT
btn_x_next      =  24;    // RIGHT
has_select_btn  = true;
btn_x_select    =  1;     // 1mm off-centre (see note below)
```

### Why x=−24 and x=+1 (not x=−22 and x=0)

OpenSCAD CGAL requires that no two subtracted shapes share an exact coplanar face or edge. The vent slots are 1.5mm wide centred at x = −15, −9.5, −4, +1.5, +7mm — their faces fall at ±0.75mm from each centre. The button hole radius is 6.25mm.

At x=−22: hole right edge = −22+6.25 = **−15.75mm** = vent slot left face at x=−15. Exact match → CGAL non-manifold.  
At x=0: hole right edge = +**6.25mm** = vent slot left face at x=+7. Exact match → CGAL non-manifold.

Moved to x=−24 (right edge −17.75mm, 2mm clear) and x=+1 (right edge +7.25mm, 1mm clear). Both `Simple: yes`, no warnings.

### Switch spec

Standard **12×12mm momentary tactile push switch**, ~₹5/pc. Examples: TS-A2PS-130, TC-1212T, or any generic "12×12 tact switch" from LCSC/Robocraze/Robu. Through-hole mount, 4-pin. Solder leads to ESP32 GPIO + GND.

---

## Known Issues / Pending Decisions

### CRITICAL — ESP32 does not fit inside outer box

The outer box internal cavity (64×54×22mm) has no dedicated space for the ESP32 PCB. After the motor clearance pocket, corner bosses, and base plate seating ledge, there is no contiguous area large enough for any standard ESP32 board.

| Board | Size | Fits? |
|---|---|---|
| ESP32 DevKit V1 | 51×29mm | ❌ No |
| ESP32-WROOM module (bare) | 18×25.5mm | ❌ No (corridors are ~15mm wide) |
| Seeed XIAO ESP32-C3 | 21×17.5mm | ❌ Borderline, no space reserved |
| ESP32-PICO-D4 | 7×7mm | ✓ Possible with custom PCB |

**Options being considered:**
- **A — Extend box:** `shell_length` 78mm → 100mm, adds 22mm bay beside motor for a bare ESP32 module. Minimal redesign.
- **B — External PCB mount:** PCB carrier clips onto outside of left/right wall alongside pogo connectors. Cleaner, more like commercial Braille displays.
- **C — Under-plate thin PCB:** Custom PCB ≤3mm flat on base plate top surface. Requires shaft clearance check.

**Decision needed before printing.**

### Minor — Motor clearance pocket bug in `outer box.scad`

```openscad
translate([0, 0, floor_thickness])
    cylinder(d=motor_clearance_diameter, h=motor_clearance_depth + 1, center=true);
```

`center=true` causes the pocket to extend both 10.5mm below z=4 (only 6.5mm below floor = not enough for 19mm motor body) and 10.5mm above z=4 (removes interior space unnecessarily). Should be a downward-only cut. Not yet fixed — depends on final motor mounting decision once ESP32 placement is resolved.

---

## Dimension Cross-Reference (Critical fits) — UPDATED Rev 2.0

| Interface | Dimension A | Dimension B | Gap |
|---|---|---|---|
| Cam OD in base plate pocket | 36.4mm cam OD | 37mm pocket | 0.3mm per side ✓ |
| Top plate on base standoffs | ±15mm standoffs | ±15mm holes | exact match ✓ |
| Linkage nub in top plate slot | 1.2mm nub | 1.2mm slot | snug (intentional) |
| Linkage foot on cam track | 2.0mm foot | 1.6mm track | foot overhangs 0.2mm each side |
| Magnet in cam pocket | 3.0mm magnet | 3.2mm pocket (dia+0.2) | 0.1mm per side ✓ |
| Hall sensor pocket | SS49E: 4×3×1.5mm | 5×4×3mm pocket | 0.5–1mm clearance ✓ |
| Motor body in motor zone | 28mm body | 40mm zone | 6mm each side ✓ |
| Motor ears in motor zone | 35mm hole spacing | 40mm zone | 2.5mm each side ✓ |
| Base plate in motor zone | 42mm plate | 40mm internal | plate uses full zone ✓ |
| Cam disc clears box midline | disc edge x=−1.8mm | midline x=0mm | 1.8mm ✓ |
| Linkage arm collision gap | 3.0mm stagger | 1.0mm arm + 0.8mm travel | 1.2mm clearance ✓ |

---

## 9. Major Redesign — Two-Zone Layout (2026-05-06)

**Trigger:** Physical inspection of 28BYJ-48 motor confirmed three blocking problems:
1. Motor shaft is **offset from body centre** (gearbox geometry) — cam pocket would be eccentric
2. Motor body is **28mm diameter, 19mm tall** — the original 28mm shell is too short to enclose it (motor would protrude 13.5mm below the floor)
3. Original **standoff height of 3.5mm** was far too short — the linkage stack alone needs 12mm clearance above the base plate

Decision: **shift motor to the left half of a wider box** and use the right half for electronics. This resolves all three problems simultaneously.

### New shell dimensions

| Parameter | Old | New | Reason |
|---|---|---|---|
| `shell_length` | 78mm | **88mm** | Motor zone (40mm) + electronics zone (40mm) + walls |
| `shell_width` | 68mm | 68mm | Unchanged |
| `shell_height` | 28mm | **42mm** | Floor(4) + motor(19) + base plate(5) + standoffs(8) + top plate(3) + margin(3) |
| `internal_length` | 64mm | **80mm** | 88 − 2×4mm walls |
| `motor_x_offset` | 0 (centred) | **−20mm** | Motor centre shifted left; cam disc edge clears midline by 1.8mm |

### Vertical stack (absolute z from box bottom) — verified

```
z = 0    box bottom (sits on desk)
z = 4    floor top  (floor_thickness = 4mm)
z = 4–23 motor body (19mm, hanging from base plate via ear screws)
z = 23   base plate bottom / motor top face (ears screw into plate underside)
z = 28   base plate top  (5mm thick)
z = 25   cam pocket floor (3mm deep from plate top)
z = 27   cam disc flat surface (2mm base resting on pocket floor)
z = 27.8 cam bump tops (0.8mm bump height)
z = 28–36 standoffs (8mm tall — the critical fix)
z = 36   top plate bottom
z = 39   top plate top surface
z = 39.0 nub flush = dot DOWN (inactive)
z = 39.8 nub top   = dot UP   (0.8mm protrusion = active Braille dot)
z = 42   shell top  (2.2mm wall above raised dot)
```

### Two-zone internal layout

```
TOP VIEW (cross-section below base plate, z = 4–23mm):

x = −44 ┌──────────────────┬──────────────────┐ x = +44
        │  MOTOR ZONE      │ ELECTRONICS ZONE │
        │  x=[−40, 0]      │  x=[0, +40]      │
        │                  │                  │
        │  ┌──────────┐    │  ┌─────────────┐ │
        │  │ 28BYJ-48 │    │  │ ULN2003 bd  │ │
        │  │ Ø28mm    │    │  │ 31×35mm     │ │
        │  │ @ x=−20  │    │  │             │ │
        │  └──────────┘    │  │ Pro Mini /  │ │
        │                  │  │ MCP23017    │ │
        │  cam+linkages    │  └─────────────┘ │
        │  above plate     │  (below plate    │
        │                  │   level only)    │
x = −44 └──────────────────┴──────────────────┘ x = +44
```

### Corner boss height correction

Old bosses: 22mm tall (`internal_depth`), starting from floor → base plate at z=26mm (wrong).
New bosses: **19mm tall** (`motor_height`), starting from floor → base plate at z=4+19=**23mm** (correct).
Base plate rests on boss tops AND on motor ears simultaneously for a rigid, located fit.

### Electronics zone PCB mounting posts

Four M2 posts added in the right half (x = +7mm, +33mm; y = ±15mm) at floor level.
Height: 4mm. Accept M2 screws from PCB mounting holes.
Designed to accept:
- ULN2003 driver board (31×35mm) — mounts on all four posts
- Arduino Pro Mini (33×18mm) — mounts on two posts alongside ULN2003

### Button wire slot (left wall)

A 6×4mm slot added to the **left wall** at btn_z height, positioned 14mm toward the back from the front face. Routes 3 signal wires + 1 GND from the front-face panel-mount buttons through to the ESP32 pod clipped on the left wall exterior. Separate from the pogo connector slot (10×8mm) to avoid interference.

---

## 10. `base_plate.scad` — Motor Dimension Corrections (2026-05-06)

All motor interface parameters were wrong. Corrected against physical motor measurements:

| Parameter | Old (wrong) | New (correct) | Effect |
|---|---|---|---|
| `base_length` | 60mm | **42mm** | Plate now spans motor zone only (was too wide for two-zone box) |
| `motor_body_diameter` | 28.3mm | **29mm** | 28mm body + 1mm tolerance |
| `motor_mount_spacing` | 31mm | **35mm** | Actual hole-to-hole distance on motor ears |
| `motor_mount_hole` | 3.4mm | **4.3mm** | 4mm ear holes + 0.3mm clearance (was M3 size — wrong) |
| `shaft_clearance` | 8mm | **7mm** | 5mm shaft + 1mm each side (was over-large) |
| `standoff_height` | 3.5mm | **8mm** | THE CRITICAL FIX — see below |

### Why standoff_height = 8mm (not 3.5mm)

With 3.5mm standoffs: top plate bottom at z=31.5mm. Linkage foot at z=27.8mm (on bump).
Available linkage height = 31.5−27.8 = 3.7mm. Linkage total height = 12mm. **Linkage is 8.3mm too tall — it would crush through the top plate.**

With 8mm standoffs: top plate bottom at z=36mm. Available height = 36−27.8 = 8.2mm for the body below the plate + 3mm plate + protrusion above = correct 12mm total path. ✓

### Hall sensor pocket repositioned

Old position: `x=+19mm, y=0` (along +X axis).
Problem: pocket extends to x=19+2.5=21.5mm, but plate edge is at x=21mm (42mm/2). Pocket overflows plate by 0.5mm → unprintable.

New position: `x=0, y=+20mm` (along +Y axis).
- Plate edge at y=25mm. Pocket extends to y=22.5mm. Clearance = 2.5mm ✓
- Still outside cam OD (18.2mm radius): sensor at r=20mm, gap = 1.8mm ✓
- Wire channel runs from pocket to +Y plate edge (25mm)
- **`magnet_angle` in `braille_cam2.scad` changed from 0° → 90°** to put the home magnet at y=+17.35mm, directly below the new sensor position ✓

---

## 11. `linkage.scad` — Staggered Arms, Corrected Height (2026-05-06)

### Problem 1 — Total height wrong

Old `riser_h = 9.0mm` (total linkage height ~13.5mm from foot to nub top).
Available gap in old design: 3.5mm standoffs + 3mm plate = 6.5mm.
Linkage was **7mm too tall**. It would pierce through the top plate and jam.

New `total_h = 12.0mm` matches the corrected stack exactly:
- Foot on cam flat (z=27mm) → nub top at z=39mm = flush with top plate ✓
- Foot on cam bump (z=27.8mm) → nub top at z=39.8mm = 0.8mm protrusion ✓

### Problem 2 — Arm collision between same-column linkages

All three linkages in a column (e.g. dots 1, 2, 3 at x=−2.4mm) had arms at the same height (`riser_h = 9mm`). When one linkage is pushed up 0.8mm by a cam bump and the adjacent one is at rest, their arms physically overlap.

**Fix: stagger arm heights by 3mm per row:**

| Row | Dots | Arm Y from foot | Lower riser | Upper riser |
|---|---|---|---|---|
| Top | 0, 3 | 3.5mm | 1.0mm | 6.0mm |
| Mid | 1, 4 | 6.5mm | 4.0mm | 3.0mm |
| Bot | 2, 5 | 9.5mm | 7.0mm | 0.0mm |

Collision clearance = stagger(3.0) − arm_h(1.0) − cam_travel(0.8) = **1.2mm** ✓

`arm_h` reduced from 1.5mm → **1.0mm** so the outermost row (arm_y=9.5mm) still fits within total_h=12mm: 9.5 + 1.0 + 0.0 + 1.5 = 12.0mm ✓

---

## 12. `top_plate.scad` — Spring Pockets Removed (2026-05-06)

Spring pockets (3.5mm dia × 1.5mm deep, on plate underside) removed for v1 prototype.

**Reason 1 — Geometry conflict:** The 3.5mm spring pocket and 1.2×3mm linkage slot are co-located at each dot position. The slot cuts entirely through the plate; the pocket cuts 1.5mm from the bottom. Where they intersect, the pocket removes the material that would form the slot walls → degenerate thin walls < 1mm → unprintable and structurally weak.

**Reason 2 — Unnecessary for prototype:** The 1mm stainless steel linkages weigh < 0.1g each. Gravity is sufficient to return them to the down position for desk-use at normal orientations. Springs will be added in v2 once a flange/shoulder feature is added to the linkage design to give the spring a seat.

**Slot chamfers kept:** The 0.3mm lead-in chamfers at each slot entry remain — they guide linkage insertion during assembly.

---

## 13. `braille_cam2.scad` — Magnet Angle Updated (2026-05-06)

```openscad
// Old:
magnet_angle = 0;    // Magnet at +X axis (x=+17.35mm, y=0)

// New:
magnet_angle = 90;   // Magnet at +Y axis (x=0, y=+17.35mm)
```

**Why:** Hall sensor pocket in base_plate.scad was moved from x=+19mm (overflows plate edge) to y=+20mm. The magnet must be at the same angular position as the sensor for homing to work. Setting magnet_angle=90° places the magnet at y=17.35mm, directly below the sensor at y=20mm. Radial gap = 20−17.35 = 2.65mm — within detection range of SS49E/A3144 for a 3mm NdFeB magnet. ✓

---

## 14. Electronics Architecture Decision (2026-05-06)

### Final architecture: Detachable ESP32 "Brain Pod" + Arduino Pro Mini per cell

Each cell contains:
- **Arduino Pro Mini 5V/16MHz** (33×18mm, Rs 120) — receives UART, drives motor, reads hall sensor and buttons
- **ULN2003A bare IC** (SOIC-16 or DIP-16, Rs 10) — replaces the full driver module (28×35mm → 20×7mm)
- **SS49E hall sensor** — homing

Attached to Cell 1 only (or any standalone cell):
- **ESP32 Brain Pod** — external box (~60×40×25mm, 3D-printed) clipping onto the left wall
- Contains: **ESP32 NodeMCU 30-pin** (51×29mm), 5V/3A barrel jack, piezo buzzer
- Connects to cell via pogo slot (UART + power)

### Power distribution

```
5V/3A wall adapter → barrel jack on Brain Pod
  → 5V rail enters Cell 1 via pogo pins (pin 1 = 5V, pin 2 = GND)
  → daisy-chains cell-to-cell through all pogo connectors
  → each cell: 5V → ULN2003 motor power (direct)
               5V → Arduino Pro Mini VCC (5V native, no regulator needed)
               5V → Hall sensor VCC
```

Peak current: 5 motors × 240mA = 1.2A + MCUs/sensors ≈ 1.5A total.
3A adapter provides 2× headroom. 50ms motor stagger in firmware keeps instantaneous draw < 700mA.

### UART protocol (daisy-chain)

```
ESP32 sends: [START][CELL_ID][CAM_ANGLE 0-63][CHECKSUM]\n
Pro Mini: if CELL_ID matches → drive motor to angle, send ACK
          if CELL_ID != mine → decrement CELL_ID, forward on TX
Button events: Pro Mini sends [BTN][MY_ID][BTN_CODE] upstream to master
```

### Hardware notes for assembly

| Item | Spec | Source | Unit cost |
|---|---|---|---|
| 28BYJ-48 stepper motor | 5V DC, 4-phase, Ø28mm×19mm body, 35mm ear spacing, 4mm holes, 5mm D-shaft | Robocraze / local | Rs 80 |
| ULN2003 driver board | 28×35mm module (use for prototype; replace with bare IC in v2) | Robocraze | Rs 40 |
| Arduino Pro Mini 5V | 33×18mm, ATmega328P, 5V/16MHz, 14 digital + 6 analog pins | AliExpress / Robocraze | Rs 120 |
| ESP32 NodeMCU 30-pin | 51×29mm, CP2102 USB-UART, WiFi+BT | Robocraze | Rs 350 |
| SS49E Hall sensor | Linear, 3-pin, 3–6V, SIP-3 package | LCSC / Robocraze | Rs 25 |
| Panel-mount pushbutton | 12mm momentary, threaded barrel, fits 12.5mm hole | Robocraze | Rs 25 |
| Pogo connector set | 4-pin spring-loaded + pad, 2mm pitch | LCSC | Rs 40/pair |
| 5V/3A wall adapter | 5.5×2.1mm barrel, regulated | Local electronics | Rs 200 |
| NdFeB magnet | 3mm dia × 2mm disc | Local / AliExpress | Rs 5 |
| Return springs (optional v2) | OD 3.5mm, ~6mm free length, compression | Local hardware | Rs 5 each |

### GPIO pin assignments (Arduino Pro Mini per cell)

| Pin | Function |
|---|---|
| D2 | ULN2003 IN1 (motor coil A) |
| D3 | ULN2003 IN2 (motor coil B) |
| D4 | ULN2003 IN3 (motor coil C) |
| D5 | ULN2003 IN4 (motor coil D) |
| A0 | Hall sensor signal (analog read) |
| D8 | BACK button (INPUT_PULLUP, active LOW) |
| D9 | SELECT button (INPUT_PULLUP, active LOW) |
| D10 | NEXT button (INPUT_PULLUP, active LOW) |
| D0/RX | UART receive (from upstream cell or ESP32 pod) |
| D1/TX | UART transmit (to downstream cell) |

**Note:** D0/D1 are hardware UART pins — do NOT use Serial.print() for debug on these pins during normal operation. Use SoftwareSerial on spare pins for debug output during development.

---

## Updated Dimension Cross-Reference (Rev 2.0)

| Interface | Dim A | Dim B | Gap | Status |
|---|---|---|---|---|
| Cam OD in base plate pocket | 36.4mm | 37mm pocket | 0.3mm/side | ✓ |
| Top plate on standoffs | ±15mm standoffs | ±15mm holes | exact | ✓ |
| Linkage nub in slot | 1.2mm nub | 1.2mm slot | snug | ✓ |
| Linkage arm collision gap | 3mm stagger | 1mm arm + 0.8mm travel | 1.2mm | ✓ |
| Linkage total height | 12mm | 39−27=12mm available | exact | ✓ |
| Motor body in zone | Ø28mm | 40mm zone | 6mm/side | ✓ |
| Motor ears in zone | 35mm span | 40mm zone | 2.5mm/side | ✓ |
| Hall sensor vs plate edge | 22.5mm pocket edge | 25mm plate edge | 2.5mm | ✓ |
| Hall sensor vs cam OD | r=20mm sensor | r=18.2mm cam OD | 1.8mm | ✓ |
| Magnet to sensor radial gap | r=17.35mm magnet | r=20mm sensor | 2.65mm | ✓ detectable |
| ULN2003 board in elec zone | 31mm board | 40mm zone | 4.5mm/side | ✓ |

---

## Section 15 — Outer Box v3.0: Motor Centred + Electronics Sub-Floor

**Date:** 2026-05-06  
**Files changed:** `outer_box.scad` (v2.0→v3.0), `base_plate.scad` (v2.0→v2.1)  
**STL verified:** `Simple: yes` for both

### Problem: motor shaft was offset from box centre

In v2.0 the motor was placed at `motor_x_offset = −20mm` (left zone).  
This is **wrong** — the cam disc must be centred over the braille dot array, which must be centred in the box. An off-centre cam means the linkages and top-plate slots are offset from any symmetric reference, making the cell asymmetric and the array invisible from the user's expected finger position.

**Fix:** `motor_x_offset = 0` → shaft and cam disc centred in box.

### Consequence: two-zone side layout abandoned

With motor centred, there is no clear "right zone" for a 31×35mm ULN2003 board beside the 28mm motor (only 13mm clearance each side). Electronics must go elsewhere.

**Solution:** Electronics pocket below motor body.

The motor body hangs 19mm below the base plate. By raising `base_plate_z` from 23mm to 32mm (adding 9mm of sub-floor space), the area directly below the motor becomes a routed pocket that fits both the Arduino Pro Mini (33×18mm) and the ULN2003 board (31×35mm) lying flat.

### New stack (z from outer box bottom)

| z (mm) | Component |
|---|---|
| 0 | Outer box bottom |
| 4 | Inner floor top |
| 4–13 | **Electronics sub-pocket** (9 mm, fits Pro Mini + ULN2003) |
| 13 | Motor body bottom |
| 32 | Motor ears / base plate bottom |
| 37 | Base plate top |
| 34 | Cam disc bottom (3 mm deep pocket from plate top) |
| 36 | Cam disc flat surface |
| 36.8 | Cam disc bump top (0.8 mm lift) |
| 45 | Standoffs top / top plate bottom |
| 48 | Top plate top surface |
| 48 | Linkage nub top when dot DOWN (flush) ✓ |
| 48.8 | Linkage nub top when dot UP (0.8 mm proud) ✓ |
| 50 | Outer box top (1.2 mm clearance above nubs) ✓ |

### Parameter changes summary

| Parameter | v2.0 | v3.0 | Reason |
|---|---|---|---|
| `motor_x_offset` | −20 mm | 0 mm | Centre shaft in box |
| `shell_length` | 88 mm | 60 mm | No side electronics zone needed |
| `shell_height` | 42 mm | 50 mm | 9 mm sub-floor for electronics |
| `base_plate_z` | 23 mm | 32 mm | = floor(4) + elec(9) + motor(19) |
| `boss_height` | 19 mm | 28 mm | = base_plate_z − floor_thickness |
| `elec_pocket_w/d` | — | 36×46 mm | New: sub-floor PCB pocket |
| `btn_x_back/next` | ±24 mm | ±20 mm | Symmetric about new centre |
| `btn_x_select` | 1 mm (vent-clear) | 0 mm | True centre |
| `internal_length` | 80 mm | 52 mm | Matches narrower shell |

### base_plate.scad v2.1

- `base_length` widened from 42 mm → 50 mm (symmetrically centred at x=0)
- 50 mm plate + 1 mm clearance each side in 52 mm internal cavity ✓
- All other dimensions unchanged

### Blender scene rebuild (2026-05-06)

Scene completely rebuilt from scratch (clean slate):
- **Two collections:** `Final_Assembly` (compact, x=0) and `Exploded_Assembly` (x=+120mm, Z-stretched)
- **Flat shading** applied to all 58 mesh objects (matches FDM printed surface appearance)
- **Exploded Z positions:** box=0, electronics=70, motor=120, baseplate=160, cam=210, linkages=250, topplate=310
- **Linkages shown in 3D assembly position** in both views: foot on cam track (at track_r), nub at dot (x,y), all 6 staggered arm heights correct
- **Hardware represented:** Motor body+shaft+ears, ULN2003 (green PCB), Arduino Pro Mini (green PCB), Hall sensor, homing magnet

### Note on springs

Return springs for braille dots were **intentionally removed for v1 prototype** (`top_plate.scad` v2.1 changelog). Gravity return is sufficient for desk-use (pins just fall when cam moves to low position). Spring pockets would create degenerate thin walls where 3.5mm pocket meets 1.2mm slot. Springs are listed in BOM as "optional v2" at Rs 5 each. Add in v2 once linkage flange geometry is finalized.

---

## Updated Dimension Cross-Reference (Rev 3.0)

| Interface | Dim A | Dim B | Gap | Status |
|---|---|---|---|---|
| Shell around cam disc | Ø36.4mm cam OD | 52mm internal (±26mm) | 7.6mm/side | ✓ |
| Boss pillars vs standoffs | (±15,±15) bosses | (±15,±15) standoffs | exact match | ✓ |
| Boss pillars vs cam pocket | r=21.2mm pillars | r=18.5mm cam pocket | 2.7mm | ✓ |
| Base plate in shell | 50mm plate | 52mm internal | 1mm/side | ✓ |
| Motor body in elec zone | Ø28mm motor | 52mm internal | 12mm/side | ✓ |
| Sub-pocket width vs motor | 36mm pocket | Ø28mm motor | 4mm/side | ✓ |
| Linkage nub through plate | 1.2mm nub | 1.2mm slot | snug fit | ✓ |
| Linkage total height | 12mm | 48−36=12mm | exact | ✓ |
| Linkage nub proud (dot UP) | 0.8mm | 1.2mm shell margin | 0.4mm | ✓ |
| Hall sensor vs new cam OD | r=20mm sensor | r=18.2mm cam | 1.8mm | ✓ |

---

## Section 16 — Full Audit Redesign (May 6 2026)

**Responding to:** Mechanical Design Audit Report (7 critical failures)
**Scope:** All SCAD files rewritten/created. All V3 features implemented. ESP32 Brain Pod added.

### 16.1 Audit Fixes Applied

| Audit Item | Issue | Fix | File |
|---|---|-----|---|
| 2.1 Electronics pocket too shallow | 9mm pocket, ULN2003 needs 12-14mm | `elec_pocket_h` 9 -> 16mm | outer_box v4.0 |
| 2.2 Hanging motor (no torque support) | Motor held only by plastic ears | 2mm mid-plate + motor retaining collar (Ø29.5mm ID, 8mm tall) | outer_box v4.0 |
| 3.1 Uncentered motor shaft (8mm offset) | Body pocket and shaft at same x=0 | Body pocket/ears offset to x=-8mm, shaft stays at x=0 | base_plate v2.2 |
| 3.2 Inadequate top plate coverage | 34x34mm plate in 52x60mm cavity | Plate resized to 52x60mm (flush fit) | top_plate v3.0 |
| 4.1 Linkage phase shift (SHOWSTOPPER) | Radial feet at different cam angles | All 6 feet at Y=0 via inline geometry | linkage v3.0 |
| 4.2 Missing spring pockets | Gravity return insufficient | 3.5mm dia x 3mm spring pockets on plate underside | top_plate v3.0 |
| 4.3 Flat rectangular Braille dots | Sharp tabs, illegible to blind users | 2mm round holes + bearing ball caps | top_plate v3.0, braille_cap v1.0 |

### 16.2 V3 Features Implemented

| Feature | Audit Ref | Implementation |
|---|---|---|
| Cam hub inversion | 6.1 | Hub extends below disc underside, top surface clear | braille_cam2 v2 |
| Pogo pin safety recess | 6.2 | Left wall pogo slot 1mm deeper | outer_box v4.0 |
| Pogo end cap | 6.2 | TPU snap-fit cover for last cell | pogo_end_cap v1.0 (NEW) |
| Magnetic snap alignment | 6.3 | 3x Ø3.2mm x 2.1mm NeFeB pockets, dock screws removed | outer_box v4.0 |
| Linkage comb guide | 6.4 | 6-slit guide block, clips on mid-plate | linkage_comb v1.0 (NEW) |
| Bearing ball Braille dots | 6.5 | 2mm SS bearing ball in cup on cap | braille_cap v1.0 (NEW) |
| Wire routing gutters | 6.8 | 4mm x 4mm channels along floor edges | outer_box v4.0 |

### 16.3 New Files Created

| File | Purpose |
|---|---|
| `cad/scad/esp32_pod.scad` | ESP32 NodeMCU 30-pin enclosure (74x38x58mm), barrel jack, USB, pogo interface, magnet snap |
| `cad/scad/braille_cap.scad` | Bearing ball dot caps (1.9mm pin, 3.5mm body, 2mm SS ball cup) |
| `cad/scad/linkage_comb.scad` | PETG guide block with 6 vertical slits (1.25mm wide) |
| `cad/scad/pogo_end_cap.scad` | TPU snap-fit cover for exposed spring pogo pins |

### 16.4 Revised Stack Table (v4.0)

| z (mm) | Component |
|---|---|
| 0 | Outer box bottom |
| 4 | Inner floor top |
| 4-20 | Electronics pocket (16mm) |
| 20-22 | 2mm mid-plate (seals electronics) |
| 22-30 | Motor retaining collar (8mm, at x=-8) |
| 22-41 | Motor body (19mm) |
| 41 | Motor ears / base plate bottom |
| 46 | Base plate top (5mm plate) |
| 43-45 | Cam disc (in 3mm pocket) |
| 45.8 | Cam bump top (0.8mm lift) |
| 54 | Top plate bottom (8mm standoffs from z=46) |
| 57 | Top plate top (4mm plate) = box top |
| 57.8 | Braille dot UP (0.8mm proud) |

### 16.5 Linkage Phase-Shift Fix (Critical)

**Problem:** v2.0 rotated each linkage by `atan2(dot_y, dot_x)` placing feet at
different cam angles. At 5.625deg/character, output was completely scrambled.

**Fix:** All 6 feet land at Y=0 on cam via:
- `arm_span(d) = sqrt((track_r(d) - dot_x(d))^2 + dot_y(d)^2)`
- `asm_ang(d) = atan2(-dot_y(d), track_r(d) - dot_x(d))`

Arm heights re-staggered (dot 1: 4.0mm, dot 4: 7.8mm) giving 2.0mm worst-case
clearance with cam bump. No collision risk.

### 16.6 ESP32 Pod Specifications

- Shell: 74 x 38 x 58mm (L x W x H)
- PCB: ESP32 NodeMCU 30-pin (51x29mm) on M2 bosses
- Power: 11mm barrel jack on top face
- Programming: micro-USB cutout on left face
- Docking: slot + 3x magnet pockets on right face (matches cell tongue)
- Pogo: 10x8mm pad recess at z=30.5mm (aligns with cell pogo_z)
- Antenna: 1.5mm thin wall + grille slots on right end

### 16.7 STL Export Verification

All 9 STLs exported via OpenSCAD CLI — **all manifold (Simple: yes)**:

| File | Size | Simple |
|---|---|---|
| braille_cam2.stl | 1334 KB | yes |
| outer_box.stl | 1267 KB | yes |
| base_plate.stl | 611 KB | yes |
| linkage.stl | 160 KB | yes |
| top_plate.stl | 1188 KB | yes |
| braille_cap.stl | 2659 KB | yes |
| esp32_pod.stl | 453 KB | yes |
| linkage_comb.stl | 37 KB | yes |
| pogo_end_cap.stl | 29 KB | yes |

### 16.8 Blender Scene Updated

`renders/braillix_assembly.blend` rebuilt with all 9 new STLs:
- **Final_Assembly** collection: all parts at correct v4.0 stack positions
- **Exploded_Assembly** collection: Z-separated for clear component visibility
- ESP32 pod positioned beside cell (x=-71mm)
- All meshes: Shade Flat, material colors assigned
- 9 materials: Shell grey, Plate dark metal, Cam blue, Linkage steel, Top cream, Cap white, Pod dark grey, Comb PETG green, EndCap TPU

---

## Section 17 — Independent Dimensional Audit #2 (2026-05-16)

**Scope:** Cross-file dimensional audit of all SCAD files after the May 6 redesign. Found 12 additional findings (3 showstopper, 3 critical, 4 moderate, 2 informational).

### 17.1 Findings Summary

| # | Severity | Issue | File(s) | Fix |
|---|---|---|---|-----|
| F1 | SHOWSTOPPER | Linkage arm_y collision (dots 1&4 both at 5.5mm) | linkage.scad | Per-dot arm_y values from reference table |
| F2 | CRITICAL | Vertical stack 1mm over-height (plate top z=58 > shell z=57) | outer_box.scad | shell_height 57→58, cascading updates |
| F3 | CRITICAL | Braille cap incompatible with linkage nub geometry | linkage.scad, top_plate.scad | Ball-on-nub approach (caps deprecated) |
| F4 | MODERATE | Mid-plate motor collar crashes into -X corner bosses | mid_plate.scad | Boss relief notch cutouts in collar |
| F5 | MODERATE | Top plate zero clearance in box (60mm in 60mm) | top_plate.scad | Plate reduced to 59×59mm |
| F6 | MODERATE | Braille cap socket depth only 0.5mm (center=true bug) | braille_cap.scad | Moot — caps deprecated per F3 |
| F7 | MODERATE | Spring pocket wall only 0.75mm thick (fragile) | top_plate.scad | Pocket 4.5mm dia, 2.0mm depth |
| F8 | MINOR | Cam hub only 2mm shaft engagement | braille_cam2.scad | hub_h reduced 4→2 for full engagement |
| F9 | MINOR | Linkage comb free-floating (no vertical lock) | linkage_comb.scad | M2 grub screw hole added |
| F10 | MINOR | Screw size mismatch (M3 boss vs M2.5 standoff) | outer_box.scad, base_plate.scad | Unified to M2.5 |
| F11 | INFO | Pod/cell magnet height — resolved by F2 fix | esp32_pod_params.scad | pogo_z updated to 31mm |
| F12 | INFO | Braille dot horizontal spacing 4.8mm (2× standard) | — | Known limitation of cam mechanism |

### 17.2 Key Parameter Changes

| Parameter | Old | New | File |
|---|-----|-----|---|
| shell_height | 57 | **58** | outer_box.scad |
| boss_height | 37 | **38** | outer_box.scad |
| mag_z | 28.5 | **29** | outer_box.scad |
| pogo_z | 30.5 | **31** | outer_box.scad |
| pogo_z_from_bot | 30.5 | **31** | esp32_pod_params.scad |
| boss screw hole d | 3.2 | **2.6** | outer_box.scad |
| corner_radius | 2 | **3** | outer_box.scad |
| plate_length/width | 60 | **59** | top_plate.scad |
| hole_dia | 2.0 | **2.5** | top_plate.scad |
| spring_pocket_dia | 3.5 | **4.5** | top_plate.scad |
| spring_pocket_depth | 3.0 | **2.0** | top_plate.scad |
| nub_w | 1.2 | **2.2** | linkage.scad |
| arm_y(0) | 2.0 | **3.5** | linkage.scad |
| arm_y(1) | 5.5 | **4.0** | linkage.scad |
| arm_y(2) | 9.0 | **9.5** | linkage.scad |
| arm_y(3) | 2.0 | **3.5** | linkage.scad |
| arm_y(4) | 5.5 | **7.8** | linkage.scad |
| arm_y(5) | 9.0 | **9.5** | linkage.scad |
| hub_h | 4 | **2** | braille_cam2.scad |
| standoff hole d | 2.6 | **2.2** | base_plate.scad |
| raise_h (nav cap) | 0.8 | **1.2** | nav_cap.scad |

### 17.3 Ball-on-Nub Dot Mechanism (replacing braille_cap)

The braille_cap.scad is **DEPRECATED**. The new approach:
- Linkage nub widened to 2.2mm (from 1.2mm) to hold a 2mm bearing ball cup
- Top plate hole widened to 2.5mm (clearance for 2.2mm nub + 0.15mm/side)
- Ball protrudes 0.2mm above plate when DOWN, 1.0mm when UP
- Dot travel = 0.8mm (matches cam lift)
- Spring in top plate pocket pushes down on nub through the hole

### 17.4 Updated Stack Table (v4.1 — shell_height=58)

| z (mm) | Component |
|---|---|
| 0 | Outer box bottom |
| 4 | Inner floor top |
| 4-20 | Electronics pocket (16mm) |
| 20-22 | Mid-plate (2mm) |
| 22-41 | Motor body (19mm) |
| 41 | Base plate bottom |
| 46 | Base plate top |
| 45 | Cam flat surface |
| 45.8 | Cam bump top |
| 54 | Top plate bottom (8mm standoffs) |
| **58** | **Top plate top = shell_height** ✓ |
| 57 | Linkage nub top (dot DOWN) |
| 57.8 | Linkage nub top (dot UP) |
| 58.2 | Ball top (dot DOWN, 0.2mm above plate) |
| 59.0 | Ball top (dot UP, 1.0mm above plate) |

### 17.5 Blind-User Ergonomic Improvements

- **Nav cap raise_h** increased 0.8→1.2mm for confident tactile identification
- **Box corner_radius** increased 2→3mm for comfortable handling
- **Braille 'F' orientation** on front face repositioned to z=43 (58−15)

---

## Section 18 — Custom PCB: Braillix Muscle Board v1.0 (2026-05-16)

**New files created in `pcb/` directory:**
- `braillix_muscle_board.kicad_pro` — KiCad 10.0.2 project file
- `braillix_muscle_board.kicad_sch` — Full schematic
- `braillix_muscle_board.kicad_pcb` — 34×44mm PCB layout (component placement + GND zone)
- `BOM_muscle_board_v1.0.txt` — Complete bill of materials with sourcing notes

### 18.1 Purpose

Replaces the Arduino Pro Mini + ULN2003 breakout board + hand-wired connections with a single 34×44mm SMD PCB. Fits in the 36×46mm electronics pocket with 1mm clearance per side.

### 18.2 Key Components

| Ref | Component | Package | Function |
|-----|---|---|---|
| U1 | ATmega328P-AU | TQFP-32 (7×7mm) | MCU (I2C slave + motor control) |
| U2 | ULN2003A | SOIC-16 | Darlington motor driver |
| Y1 | 16 MHz crystal | HC49-4H | MCU clock |
| C1-C4 | 22pF / 100nF | 0402 | Crystal load + VCC decoupling |
| C5 | 100µF / 10V | SMD elec 5×5.3mm | Motor bulk bypass |
| D1 | SS14 | SMA (DO-214AC) | Reverse polarity protection |
| J1 | 1×04 header | 2.54mm | Pogo interface (+5V, GND, SDA, SCL) |
| J2 | JST XH 5-pin | B5B-XH-A | 28BYJ-48 motor connector |
| J3 | 1×03 header | 2.54mm | Hall sensor (VCC, GND, SIGNAL) |
| J4 | 2×03 header | 2.54mm | AVR ISP programming |

### 18.3 Design Changes from Original Architecture

- **Protocol changed from UART to I2C:** Each cell is an I2C slave (addresses 0x20-0x27 via solder jumpers on PB0-PB2). No more daisy-chain forwarding.
- **I2C pull-ups:** 4.7K on SDA/SCL, enabled via solder jumper on last cell only.
- **Board specs:** 2-layer, 1.6mm FR4, 1oz Cu, HASL lead-free.

### 18.4 DRC Results

KiCad 10.0.2 DRC validation:
- **0 electrical errors** (no shorts, no clearance violations)
- **50 unconnected items** — expected, traces to be routed in KiCad GUI
- **21 lib_footprint_mismatch** — cosmetic (inline vs library footprints)
- **4 silk_over_copper** — cosmetic (auto-clipped during Gerber export)

### 18.5 Estimated Cost

- BOM: ~$3.50 per board (LCSC/JLCPCB pricing, qty 10+)
- PCB fabrication: ~$0.40/board (JLCPCB, 5-board MOQ)
- Total per cell: ~$3.90 (vs ~$5+ for discrete modules + hand wiring)

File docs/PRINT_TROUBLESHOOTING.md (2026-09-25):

> **2026-08-19 release gate:** Use `PRINT_RELEASE_2026-08-19.md` and its checked Orca G-code.
> This document is historical troubleshooting reference. The final top plate waits for its
> interface coupon, and the rebuilt snap end cap is TPU 95A only - never PETG.
# Braillix — FDM Print Troubleshooting & Cura Settings Guide

**Printer:** Anycubic Kobra Neo (0.4mm nozzle, direct-drive extruder, 220×220 bed)
**Slicer:** Ultimaker Cura
**Material:** Numakers PETG-HS — nozzle 230–240 °C, bed 80 °C
**Resin parts** (cam, linkages, nav caps, dot insert) go to an online SLA service and are **not** covered by the Cura settings here — see §2.8.

All Cura setting names below are written **exactly as they appear in the Cura UI**. If you can't find one, set settings visibility to **Expert / All** (gear icon next to the search box in the Print Settings panel), or type the name into the search box.

> ⚠️ **Correction to the previous version of this file.** An earlier draft said to flip `outer_box` 180° and print it rim-down so the printer "bridges across the gap". **That is wrong and will produce a much worse part.** The cavity is 60mm wide — nothing bridges 60mm — and flipping puts the four 37mm corner bosses in the air, tip-first, exactly the bosses that already snapped on the real print. Print `outer_box` **open side UP**. Full reasoning in §2.1.

---

## 0. The one-line answer

> **You should not have had supports on `outer_box` at all.** The current part uses self-supporting teardrop magnet pockets, real open pogo windows, and gusseted bosses. There are no printed-in sacrificial window bridges. Turning on **Generate Support** with **Support Placement = Everywhere** fills the internal cavity and can weld around bosses and ledges.

Sections 1 and 2 cover both halves of the fix: how to make supports removable when you genuinely need them, and how to orient each part so you never need them.

---

## 1. Why the supports were unremovable

Welded supports are almost never bad luck. They are a small set of settings, and one of them dominates.

### 1.1 Support Z Distance — the single biggest cause

**Cura:** *Support* → **Support Z Distance**, which expands into **Support Top Distance** and **Support Bottom Distance**.

This is the deliberate air gap between the top of the support and the underside of the part. If it is **0**, the support is not a support — it is *part of the model*, extruded in the same continuous motion, fully bonded. No tool will get it out cleanly; you will tear the part surface off instead.

Cura's default is `0.2mm`, and a lot of profiles (including several community Kobra Neo profiles) ship it at `0` or `0.1`, because that gives the prettiest overhang surface **on PLA**.

**PETG needs a LARGER Z distance than the PLA defaults every guide assumes.** PETG has much higher interlayer adhesion and stays tacky longer at 235 °C, so it happily bonds across a gap that PLA would have left as a clean break. The gap must also be an exact **multiple of your layer height**, or Cura rounds it and you get something you didn't ask for.

| Setting | PLA default | **Use for PETG @ 0.2mm layers** | Notes |
|---|---|---|---|
| **Support Z Distance** | 0.2 | **0.4** | = 2 layers. Master value; fills in the two below. |
| **Support Top Distance** | 0.2 | **0.4** | The gap *under* the part. This is the one that welds. Never below 0.3 on PETG. |
| **Support Bottom Distance** | 0.2 | **0.2** | Gap where support lands *on* the part. Keep smaller — too big and the tower is unstable. |

At **0.16mm** layers use Top Distance `0.32`; at **0.12mm** use `0.36` (3 layers). Always a whole number of layers.

*Trade-off, stated honestly:* a 0.4mm gap means the first layer bridging over the support droops slightly, so the supported face is visibly rougher than with a 0.2 gap. That is the correct trade. A rough face you can sand beats a welded face you destroy trying to clean.

### 1.2 Support Pattern — grid is the trap

**Cura:** *Support* → **Support Pattern**

- **Grid** (the default in several profiles) prints lines in **both X and Y**, and every intersection is a welded junction. The result is a rigid 3D lattice with the shear strength of a solid block. That is exactly the "rock solid, could not be plucked out" you hit. In a deep pocket like the `outer_box` cavity, grid support is functionally a second solid part inside your part.
- **Zig Zag** prints one continuous line snaking back and forth in **a single direction**, with no cross-bracing. It is weak in shear, so a support wall collapses and comes out as one connected ribbon — grab one end with pliers and unzip it.
- **Lines** is even easier to remove but topples on tall supports.
- **Triangles / Cross / Concentric / Gyroid** — not for removability. Triangles is the worst of the lot: grid plus diagonals.

**Set Support Pattern = Zig Zag.** There is no case in this project where Grid is the right answer.

### 1.3 Support Density

**Cura:** *Support* → **Support Density** (and the derived **Support Line Distance**)

Cura defaults to 15–20 %. That is far denser than needed, and it packs lines close enough that neighbouring lines fuse sideways into solid sheets.

- **Support Density: 8 %** for PETG (≈5mm Support Line Distance at 0.4mm line width). Go to 10 % only if a tower visibly topples.
- **Support Wall Line Count: 0.** Quietly lethal. If it is 1 (a common default), Cura draws a solid perimeter around every support region, turning your loose 8 % lattice into a **rigid closed tube**. At 0, the support has no shell and no hoop strength.
- **Support Infill Layer Thickness: 0.2** (= layer height). Multiples print faster but come out stiffer.
- **Gradual Support Infill Steps: 0.** Gradual infill *densifies* support near the part — the exact opposite of what you want.

### 1.4 Support Interface / Roof

**Cura:** *Support* → **Enable Support Interface**, which reveals **Enable Support Roof**, **Enable Support Floor**, **Support Interface Thickness**, **Support Interface Density**, **Support Interface Pattern**.

The interface (roof) is a dense, near-solid raft at the very top of the support, right under the part. It makes the supported surface much smoother — and much harder to remove, because you replaced a few thin line-contacts with a solid plate pressed against the overhang.

**On PETG, start with Enable Support Interface = OFF.** With 0.4mm Top Distance and Zig Zag, supports then peel by hand.

If a surface genuinely needs the finish (none of the Braillix PETG parts do, in the orientations in §2), enable it but detune it:

| Setting | Value |
|---|---|
| Enable Support Interface | On |
| Enable Support Roof | On |
| Enable Support Floor | **Off** — floors weld to the part's *top* surfaces, pure downside |
| Support Interface Thickness | 0.8 (4 layers) |
| **Support Interface Density** | **40–50 %** (Cura defaults to 100 % = a solid welded plate) |
| Support Interface Pattern | **Zig Zag** (default is Concentric — a nightmare to pick out) |
| Support Top Distance | keep **0.4** — don't let a "quality" profile drop it |

### 1.5 Support X/Y Distance

**Cura:** *Support* → **Support X/Y Distance**, **Support Distance Priority**, **Minimum Support X/Y Distance**.

The horizontal gap between support and part. It governs supports growing *alongside* vertical walls — exactly what happened around your four Ø7.8mm corner bosses and along the cavity walls.

- **Support X/Y Distance: 0.8mm** (2 × nozzle width). Cura's 0.7 default is borderline on PETG; 0.8 is a clean two-line gap. Below ~0.5 the support and the wall extrude into each other and become one object.
- **Support Distance Priority: `Z overrides X/Y`.** This matters more than it sounds. With `X/Y overrides Z` (Cura's default) the horizontal gap wins at the edges of an overhang, which *cancels the Z gap right where support meets the underside of the part* — so the outermost ring of support welds to the part edge even though you set Top Distance correctly.
- **Minimum Support X/Y Distance: 0.4** (used when Z overrides X/Y; keeps support from touching walls at all).
- **Support Horizontal Expansion: 0** — a positive value grows support footprints toward your part.
- **Support Join Distance: 2.0** — merges nearby support islands so you pull out fewer separate chunks.

### 1.6 Support Placement — the setting that created the problem

**Cura:** *Support* → **Support Placement**: `Everywhere` | `Touching Buildplate`

- **`Everywhere`** lets support generate on top of *the model itself*. On `outer_box` printed open-side-up that means Cura fills the whole internal cavity, builds on the electronics-pocket floor, on the mid-plate ledge at z=20, around all four corner bosses, and around the muscle-board bosses, cable hooks and wire guides. Every one of those contacts is a weld point somewhere your fingers and pliers cannot reach. **This is why it was impossible.**
- **`Touching Buildplate`** only allows support rising from the bed. It cannot generate inside a closed pocket. **Use this.**

Also raise **Support Overhang Angle** from `45°` to **`50–55°`** — PETG on this printer holds 50° unsupported, so 45 is over-supporting. And set **Minimum Support Area: 3–5 mm²** to kill the one-line slivers that are impossible to grip.

**Support Structure:** `Normal` is right for these boxy parts. `Tree` touches less surface and reaches awkward spots — only worth trying if you ever print the pod in an unusual orientation.

Finally: **Enable Support Brim = Off** for PETG on a heated bed. A support brim is welded to the bed *and* to the support — a second thing to chisel off.

### 1.7 Complete "removable support" preset (PETG, 0.2mm layers)

Apply only when a part actually needs support (per §2: **none of them do**).

```
Generate Support                    On
Support Structure                   Normal
Support Placement                   Touching Buildplate
Support Overhang Angle              52
Support Pattern                     Zig Zag
Support Wall Line Count             0
Support Density                     8 %
Support Horizontal Expansion        0
Support Infill Layer Thickness      0.2
Gradual Support Infill Steps        0
Enable Support Interface            Off
Support Z Distance                  0.4
  Support Top Distance              0.4
  Support Bottom Distance           0.2
Support X/Y Distance                0.8
Support Distance Priority           Z overrides X/Y
Minimum Support X/Y Distance        0.4
Support Stair Step Height           0.2
Support Join Distance               2.0
Minimum Support Area                3
Enable Support Brim                 Off
```

### 1.8 What is NOT support (do not throw these away)

Two CAD features *look* like support in the slicer preview and must survive printing until you deliberately remove them:

- **Current pogo and USB openings are real open geometry.** No sacrificial bridge module remains. Do not preserve, score, or snap any 0.6 mm ledge; remove loose strings only. The teardrop magnet-pocket roof below is intentional self-supporting geometry.
- **Teardrop magnet pockets.** The 8.4mm horizontal magnet pockets have a 45° peaked roof instead of a round top, because round horizontal holes in vertical walls **fused closed** on the fit-test print. The teardrop is self-supporting — it needs no support and must not be "fixed".

---

## 2. Per-part settings — orientation is the real fix

Every PETG part in this project is designed to print **with zero supports**, in the orientation documented in its SCAD header. If your slice shows support, either the orientation is wrong or Generate Support is simply on.

Common base settings for all PETG parts unless a table below overrides them:

| | |
|---|---|
| Printing Temperature | 235 °C (range 230–240; go toward 230 if stringing) |
| Printing Temperature Initial Layer | 240 °C |
| Build Plate Temperature | 80 °C |
| **Wall Line Count** | **5** — from the v6.1 fit-test: 5 perimeters is what makes the small bosses print solid |
| Top Layers / Bottom Layers | **5 / 5** |
| Top/Bottom Thickness | 1.0mm |
| Infill Pattern | Cubic (or Gyroid) |
| Enable Retraction | On — **Retraction Distance 1.5–2.5mm @ 35 mm/s** (Kobra Neo is **direct drive**; do NOT use the 5–6mm Bowden numbers you'll find online) |
| Print Speed | 45 · Outer Wall 25 · Inner Wall 40 · Top/Bottom 30 · Initial Layer 20 (mm/s) |
| Fan Speed | 40 % · Initial Fan Speed 0 % · Regular Fan Speed at Layer 3 |
| Build Plate Adhesion Type | Brim 8mm for tall parts, Skirt for flat plates |
| **Generate Support** | **Off** |

### 2.1 `outer_box.stl` — open side **UP**

| | |
|---|---|
| **Orientation** | **Floor flat on the bed, open cavity facing UP.** As exported; no rotation. |
| **Supports** | **NO** |
| Layer Height | 0.2mm |
| Infill Density | 25 % |
| Wall Line Count | 5 |
| Adhesion | Brim 8mm (68×68 footprint, 54mm tall, PETG — cheap insurance) |

**Open-side-down vs open-side-up — settled:**

Printed **open-side-DOWN** (rim on the bed), the 4mm floor becomes a **ceiling spanning the full 60×60mm cavity**. Nothing bridges 60mm — Cura *must* fill the whole cavity with support, which is a worse version of the problem you already had. And it gets worse:

- The four **Ø7.8 × 37mm corner bosses** would hang down from that ceiling as free-standing pillars printed tip-first, each needing its own support tower. These bosses **already snapped on the real print**; v6.2 added gusset cones at their **base** precisely because that is where the load is. Printing upside down puts the weak tip on the bed and the gusset in the air — mechanically backwards.
- The **mid-plate ledge at z=20**, the **electronics pocket floor**, the **cable hooks**, the **muscle-board bosses** and the **wire gutters** all invert into overhangs.
- The **rim** — the flat top face at z=54 that the `top_plate` over-cap seats on — would be squashed against the bed with elephant's foot, ruining the seating plane for the entire cam/standoff/top-plate stack.

Printed **open-side-UP** (the shipped design intent), the floor is the bed layer, the walls rise vertically, the bosses grow from their gusseted base upward, the pogo windows are handled by the printed-in 0.6mm bridges, and the magnet pockets are teardrops. **Nothing in the part exceeds a 50° overhang.** The only mild overhangs are the 1.5mm-wide mid-plate ledge and the 1.5mm cable-hook lips — both short enough to bridge cleanly at 40 % fan.

If Cura still wants support with the part open-side-up, the cause is **Support Placement = Everywhere**, not the geometry. Turn Generate Support off and re-preview.

### 2.2 `esp32_pod_shell.stl` — upright, open top **UP**

| | |
|---|---|
| **Orientation** | Upright, **open top facing UP** (per the `esp32_pod_shell.scad` header) |
| **Supports** | **NO** |
| Layer Height | 0.2mm |
| Infill Density | 25 % |
| Wall Line Count | 5 |
| Adhesion | Brim 8mm |

The v6.1b rebuild made the **switch cages** (side fins + a solid back wall rising from the floor) and moved the **lid screw bosses** to x=±27.5 so they embed 2mm into the wall — both changes exist *specifically* so nothing floats and nothing needs support. With support **Everywhere**, Cura packs the pod interior and welds into the switch cages and the header channels, which are the two things you can't clean out afterwards. The USB cutout has its own 0.6mm printed bridge; nav-button holes and magnet pockets are teardropped.

### 2.3 `esp32_pod_lid.stl` — outer face **DOWN**

| | |
|---|---|
| **Orientation** | **Flat, cosmetic/outer top face DOWN on the bed** (per `esp32_pod_lid.scad`: "Print orientation: flat (face down)"). The ±Y skirt and the barrel-jack cradle then point upward and are self-supporting. |
| **Supports** | **NO** |
| Layer Height | 0.2mm |
| Infill Density | 30 % |
| Wall Line Count | 5 |
| **Top Layers / Bottom Layers** | **6 / 6** — see note |

**From the v6.1b fit-test:** the lid's recessed face **printed as exposed infill** on the real part. That is a slicer problem, not a CAD problem — too few solid layers over a shallow recess. Top Layers ≥ 5 (6 is safer at 30 % infill). Face-down also means the ⠿ pod-ID marker and the P/S/N labels form against the glass, giving the sharpest possible edges. Set **Initial Layer Horizontal Expansion = −0.1mm** so elephant's foot doesn't smear them.

### 2.4 `base_plate.stl` — flat, standoffs **UP**

| | |
|---|---|
| **Orientation** | Flat, **motor/cam side and the 8mm standoffs facing UP**, plain underside on the glass |
| **Supports** | **NO** |
| Layer Height | 0.2mm |
| Infill Density | **40 %** — this plate carries the motor and the whole cam/linkage stack |
| Wall Line Count | 5 |

The underside ribs were **deleted in v6.1b**, partly for exactly this reason: printing flat put the ribs on the bed and bridged the plate body over 3mm of air, giving a waffled underside. It is now a solid 5mm plate — put the plain face on the glass and you get a flat, dimensionally-true reference surface for free. The cam pocket (Ø46 × 3mm), motor seat and shaft clearance are all pockets opening **upward**: no support. Ream the four Ø4.3mm motor mount holes (§4.4).

### 2.5 `mid_plate.stl` — flat

| | |
|---|---|
| **Orientation** | Flat on the bed (2mm plate; put the face you care about down) |
| **Supports** | **NO** |
| Layer Height | 0.16mm — at 0.2 a 2mm plate is only 10 layers; 0.16 gives 12–13 and a cleaner edge on the relief slot |
| Infill Density | 40 % (largely academic — at 2mm the skins nearly meet) |
| Wall Line Count | 4 |

Every feature is a through-cut: boss clearance holes, shaft hole, motor wire slot, the ULN2003 relief slot at (+X,−Y), the edge notches. Nothing overhangs. Thin flat plates are the parts most likely to warp in PETG — use a Skirt, keep the part off the bed edges, and add a 5mm Brim if a corner lifts.

### 2.6 `top_plate.stl` — reading face **UP** — *this is now a PETG part*

**HOLD for final use until `top_interface_coupon.gcode` passes with the real M2.5 screw and resin insert.**

| | |
|---|---|
| **Orientation** | Flat, **recessed reading face UP**, plain underside on the bed |
| **Supports** | **NO** |
| Layer Height | **0.16mm** — this is a surface a user touches |
| Infill Density | 40 % |
| Wall Line Count | 5 |
| Special | **Enable Ironing: On** for the finger-pad recess |

**This part changed in v7.2 and the workshop README hasn't caught up.** `top_plate` used to be resin. All the precision features — six 1.7mm dot holes, six 2.2mm spring bores with 0.4mm dividing walls (one nozzle width, genuinely un-FDM-able) — moved out into `dot_insert.scad`, a ~15mm resin tile that glues into a rebate. What remains in `top_plate` is an 11.2mm square opening and a 15.2mm rebate: ordinary FDM geometry. **Print `top_plate` in PETG; order `dot_insert` from the SLA service.**

Reading-face-up means the finger-pad recess, the screw counterbores and the insert rebate are all pockets cut downward from the top — no support anywhere. The rebate floor is the **glue shelf** for the resin insert, so it must be flat and at the right depth; that is what the ironing and 0.16mm layers buy you. **Do not apply Hole Horizontal Expansion to this part** — the rebate is a fit surface with only 0.1mm/side designed clearance.

### 2.7 `pogo_end_cap.stl` — flat, open side **UP**

| | |
|---|---|
| **Orientation** | Flat, open/hollow side facing UP |
| **Supports** | **NO** |
| Material | **TPU 95A ONLY** (the hollow tongue and barbs require controlled flex) |
| Layer Height | 0.16mm |
| Infill Density | 30 % |
| Wall Line Count | 3 |

**TPU profile gate:** Do not reuse the PETG G-code. Wait for the exact TPU 95A spool, then use its manufacturer temperatures with roughly 20-25 mm/s, 0.5-1 mm retraction, 3-4 walls, no support, and no ironing. Validate the cap in `pogo_receiver_coupon` for 20 insertion/removal cycles.

### 2.8 Resin parts — hand these to the SLA service, not to Cura

| Part | Qty | Orientation to request | Material |
|---|---|---|---|
| `braille_cam` | 1 | Hub DOWN, cam tracks UP | Tough / ABS-like |
| `linkage` | 8 (6 + 2 spares) | Flat on the plate, all plies on one plate | Tough / ABS-like |
| `nav_cap` | 3 | Flat, dome UP | Tough / ABS-like |
| `dot_insert` | 1–2 | Flat, holes vertical | Tough / ABS-like |

Explicitly specify **TOUGH or ABS-like resin, not standard brittle resin** — the linkages are load-bearing. Resin handles the 0.1mm gaps and 1.7mm holes that FDM cannot; **do not apply FDM tolerance edits to these files** (no hole reaming, no gap widening).

### 2.9 Quick reference

| Part | Material | Orientation | Support | Layer | Infill | Walls |
|---|---|---|---|---|---|---|
| `outer_box` | PETG | Open side **UP** | **No** | 0.2 | 25 % | 5 |
| `esp32_pod_shell` | PETG | Upright, open top **UP** | **No** | 0.2 | 25 % | 5 |
| `esp32_pod_lid` | PETG | Outer face **DOWN** | **No** | 0.2 | 30 % | 5 |
| `base_plate` | PETG | Flat, standoffs **UP** | **No** | 0.2 | 40 % | 5 |
| `mid_plate` | PETG | Flat | **No** | 0.16 | 40 % | 5 |
| `top_plate` | PETG after interface coupon | Reading face **UP** | **No** | 0.16 | 40 % | 5 |
| `pogo_end_cap` | TPU 95A only | Flange down, hollow tongue **UP** | **No** | 0.16-0.20 | spool-specific | 3-4 |
| `braille_cam`, `linkage`, `nav_cap`, `dot_insert` | Resin (SLA) | see §2.8 | — | — | — | — |

---

## 3. Internal surface roughness

"Rough where components have to mount" has three separate causes on these parts. Fix the right one.

### 3.1 Cause A — torn support scars

If the surface was supported, the roughness **is** the support. Fix it upstream with §1 and §2 (mostly: don't support at all). Nothing in post-processing fully recovers a face that had support welded to it.

### 3.2 Cause B — upward-facing internal floors printed over infill

The `outer_box` electronics-pocket floor, the mid-plate ledge, the lid recess and the muscle-board boss seats are all **top surfaces**. If Cura doesn't put enough solid layers over the infill beneath, you get pillowing — visible infill lines and a dimpled surface. That is precisely what happened to the lid recess on the fit-test print.

| Setting | Value | Why |
|---|---|---|
| **Top Layers** | **5** (6 on the lid) | 5 × 0.2 = 1.0mm of solid skin. Cura's default 4 at 20 % infill isn't enough for PETG. |
| **Bottom Layers** | **5** | |
| Top/Bottom Thickness | 1.0mm | |
| **Infill Density** | **≥ 25 %** | Skin quality is a function of how far the first solid layer must bridge. At 15 % infill, no number of top layers saves you. |
| Infill Pattern | Cubic | Better skin support than Lines/Zig Zag, less stringy than Gyroid on PETG |
| **Enable Ironing** | **On** for `top_plate`, `esp32_pod_lid`, `base_plate` | §3.4 |
| Top/Bottom Speed | 30 mm/s | Slower = flatter skin |
| Skin Overlap Percentage | 10 % | Fuses the skin into the walls |

### 3.3 Cause C — downward-facing internal surfaces (the hard one)

Undersides of ledges (mid-plate ledge, hook lips, pocket ceilings) are printed into air. They will always be the worst surfaces on the part. Improve them with:

| Setting | Value | Why |
|---|---|---|
| **Layer Height** | 0.16 or 0.12 on critical parts | Smaller stair-steps on every sloped surface, shorter unsupported span per layer |
| **Enable Bridge Settings** | **On** | Cura applies dedicated bridging behaviour on detected spans |
| Bridge Wall Speed / Bridge Skin Speed | 15–20 mm/s | Slow bridges droop far less |
| **Bridge Fan Speed** | **100 %** | Full cooling *only* on bridges — freezes the extrusion mid-air without wrecking adhesion elsewhere |
| Bridge Skin Density | 100 % | |
| **Regular Fan Speed** | **40 %** | PETG-specific. 100 % fan everywhere kills interlayer adhesion (that's the brittle, delaminating PETG everyone complains about); 0 % gives sagging overhangs and stringing. 40 % is the working compromise on a Kobra Neo — test 30–50 %. |
| Minimum Layer Time | 6 s | Lets small cross-sections cool before the next layer |
| Lift Head | Off | Leaves blobs on a single-part print |

Also **drop the nozzle to 230 °C** if overhangs droop — the whole 230–240 band works with this filament, and the low end is measurably cleaner on overhangs at some cost in layer strength.

### 3.4 Ironing — where it actually applies

**Cura:** *Shell* → **Enable Ironing**, **Iron Only Highest Layer**, **Ironing Pattern**, **Ironing Flow**, **Ironing Inset**, **Ironing Line Spacing**, **Ironing Speed**.

Ironing re-runs the hot nozzle over finished **top surfaces** with almost no extrusion, melting the ridges flat. Know the limits:

- It works **only on upward-facing flat top surfaces**. It does **nothing** for downward-facing or vertical surfaces — it will not fix §3.3.
- It roughly doubles the time spent on those surfaces.
- On PETG it can drag and leave stringy boogers if the flow is too high. Start low.

| Setting | Value |
|---|---|
| Enable Ironing | On (per-part: `top_plate`, `esp32_pod_lid`, `base_plate`) |
| Iron Only Highest Layer | **Off** — you want the internal pocket floors ironed too, not just the topmost layer |
| Ironing Pattern | Zig Zag |
| **Ironing Flow** | **8 %** (Cura default 10 %; drop to 6 % if it blobs) |
| Ironing Line Spacing | 0.1mm |
| **Ironing Inset** | **0.35mm** — keeps the nozzle from pushing melt over the outer wall edge |
| Ironing Speed | 20 mm/s |

**Do not iron** `outer_box` or `esp32_pod_shell` — their floors are deep inside a box, the nozzle will drag on the walls, and those surfaces are hidden anyway.

### 3.5 Mounting surfaces specifically

For the muscle-board boss tops, the motor seat and the mid-plate ledge, the practical answer is mechanical rather than slicer-based: after printing, run a **flat needle file**, or a **chisel-blade hobby knife held flat**, across the seat and check against a steel rule. Two minutes of filing beats an hour of slicer tuning, and these are non-cosmetic surfaces.

---

## 4. Post-processing

### 4.1 Support removal (and sacrificial-bridge removal)

**Tools worth owning** — all cheap, all easy to source:

- **Flush / side cutters** — the primary tool. Get in at the base of a support wall, snip, then peel.
- **Needle-nose pliers** — grip and roll support ribbons out of pockets.
- **Dental pick set / hook probe** (~₹150 for six) — the only thing that reaches into 6–10mm pockets.
- **Hobby knife** (X-Acto / scalpel #11) plus spare blades.
- **Deburring tool** (swivel blade) — the single best tool for cleaning hole edges and cut lines.
- **Small flat + round needle files.**

**Technique:**

1. **Do it while the part is warm**, straight off the bed (~40–50 °C). PETG is far less brittle warm — supports peel instead of shattering into fragments you then have to pick out.
2. Start at an **edge or corner** of a support region, never the middle. With Zig Zag at 8 % you can usually catch the ribbon end and unzip the whole wall.
3. **Never lever against the part.** Lever against your own pliers or a bench block. Prying off a boss is how bosses snap — and these bosses have already snapped once.
4. The **freezer trick** (20 min at −18 °C; differential contraction pops supports loose) works well on PLA and only somewhat on PETG. Try it before resorting to force — it costs nothing.
5. If a support is genuinely welded, **stop**. Cut it flush with a knife, leave the stub, sand it. Pulling harder takes part material with it.

**No sacrificial bridge material remains in the current outer box or pod.** The windows are real open geometry. Remove only loose strings; do not cut or snap a structural wall. Verify the 10 x 8 mm pogo opening with `pogo_receiver_coupon` before printing the enclosure.

### 4.2 Sanding

PETG **gums up dry paper** and melts under a powered sander. Wet-sand by hand.

| Stage | Grit | Use |
|---|---|---|
| Knock down support scars, blobs, seams | **180–240** | Dry or wet, light pressure, on a sanding block |
| Blend | **400** | **Wet** — water with a drop of dish soap |
| Smooth | **800** | Wet |
| Optional sheen | 1200–2000 | Wet; only for the pod lid / top plate if you care cosmetically |

Rules:
- **Wet sand from 400 up.** Stops the paper clogging and stops heat glazing the surface.
- **Back the paper with a block** on flat surfaces — fingers give you a wavy surface.
- **Do not sand fit surfaces:** the `top_plate` insert rebate, magnet pockets, boss seats, mid-plate ledge, motor seat, cam pocket. All have ≤0.4mm designed clearance and sanding blows the tolerance.
- **No acetone smoothing** — PETG doesn't respond. **No flame or heat-gun polishing** — PETG blisters and deforms long before it polishes.
- Wear a mask. PETG dust is fine and unpleasant.

### 4.3 Stringing

PETG strings. Normal, and mostly fixable. **Work through these in order:**

1. **Dry the filament.** PETG is strongly hygroscopic and this is the #1 cause. 60–65 °C for 4–6 h in a filament dryer or food dehydrator; an oven works if it genuinely holds ≤65 °C. Tell-tale signs of wet filament: popping/crackling at the nozzle, and a foggy, rough surface as well as strings.
2. **Drop the nozzle temperature** 240 → 235 → 230 in 5° steps, printing a two-tower stringing test at each. Stop before layer adhesion suffers.
3. **Retraction — direct-drive numbers.** Retraction Distance **1.5–2.5mm**, Retraction Speed **35 mm/s**, Retraction Minimum Travel **1.0mm**, Maximum Retraction Count **25**, Minimum Extrusion Distance Window **1.0mm**. Ignore any guide quoting 5–6mm — that is Bowden advice and on the Kobra Neo's direct extruder it just grinds a flat into the filament.
4. **Combing Mode = `Within Infill`** (or `Not in Skin`) — keeps travel moves inside the part where strings don't show, and cuts the retraction count.
5. **Travel Speed 150 mm/s** — less time for ooze to form a string.
6. **Enable Coasting** (*Experimental*): **Coasting Volume 0.05–0.08 mm³**, Minimum Volume Before Coasting 0.8. Stops extruding just before the end of each line so nozzle pressure bleeds off.
7. **Z Hop When Retracted: Off** for stringing purposes (it slightly increases ooze). Enable it only if the nozzle is knocking into printed parts.

**Clean up what's left:** a **heat gun on low, held 15–20cm away, moving constantly, 2–3 seconds at a time.** Wispy strings vanish well before the part surface reaches deformation temperature. This works remarkably well on PETG — practise on a failed print first. Do **not** use a lighter: soot and localised melting.

### 4.4 Cleaning small holes and pockets

**Holes on this printer print 0.2–0.3mm undersize** — measured on the fit-test, which is exactly why the CAD pilots were already enlarged (M2: 1.7 → 2.0, M2.5: 2.1 → 2.3).

**Slicer-side compensation (optional):**
*Cura:* **Hole Horizontal Expansion = 0.10–0.15mm**. This offsets hole walls outward — 0.1 here grows a hole's **diameter** by ~0.2mm, which matches the measured error. Also set **Hole Horizontal Expansion Max Diameter = 12mm** so it applies to fastener holes but leaves the large cutouts and the 8.4mm magnet pockets alone (those already carry designed clearance and must not grow).
**Test before you commit:** print a small coupon with 1.7 / 2.0 / 2.3 / 4.3mm holes, measure with calipers, and set the expansion to half the diameter error you measure. Don't discover it on a 3-hour print.

**Drill-side clean-up — do this regardless.** Buy an **HSS micro drill set 0.5–3.0mm** (~₹300) and a **pin vise / hand chuck** (~₹200).

| Feature | As designed | Drill / ream with |
|---|---|---|
| `dot_insert` dot holes | Ø1.7 | **1.7mm** — resin part, shouldn't need it. Only if a dome binds. |
| M2 self-tap pilots (`outer_box` muscle-board bosses 1.7; pod lid bosses 2.0) | Ø1.7–2.0 | **1.6mm** if you want the screw to cut its own thread; **2.05mm** for a clearance hole |
| M2.5 corner-boss pilots (`outer_box`, 2.3) | Ø2.3 | **2.3mm** to true it; **2.6mm** for a clearance pass |
| Motor thread-forming pilots (`base_plate`, coupon-select 3.3/3.4/3.5) | selected coupon size | Do not ream to clearance size; use the winning pilot and M4x5 only |
| Cam shaft clearance / standoff bores | Ø6–10 | Round needle file — not a drill |
| Magnet pockets (8.4 × 1.2, teardrop) | Ø8.4 | **Do not drill.** Test-fit the 8 × 1mm magnet; if tight, a few passes with a round needle file or a rolled strip of 240 grit. Drilling destroys the teardrop roof. |
| Pogo window (10 x 8 through 4 mm wall) | rectangular | Test the receiver coupon; remove loose strings only, never cut structural wall |
| Spring bores (Ø2.2, 0.4mm walls) | Ø2.2 | **Resin insert only.** Never attempt in PETG — that is the entire reason `dot_insert` exists. |

**Drilling technique for PETG:**
- **Turn by hand in a pin vise.** A power drill grabs, melts, pulls the hole oversize and oval, or rips the part out of your hand.
- Enter from **the side that matters** (the fit side) and back the part with scrap so the exit doesn't blow out.
- Clear swarf often — PETG comes off as one long ribbon that jams the flutes.
- Deburr both faces afterwards with the swivel deburring tool, or by spinning a larger bit **by hand** in the hole mouth.

**Pockets** (electronics pocket, header channels, switch cages, wire gutters): dental pick + flat needle file, then blow out with compressed air. Check depth with digital calipers before dropping components in. Don't force a fit — find which surface is proud and remove *that*.

---

## 5. Settings to change RIGHT NOW in Cura

Apply these before your next slice. Ordered by impact.

1. **Generate Support → OFF.** Every Braillix PETG part is designed to print without it. This alone fixes your main problem.
2. **Support Placement → `Touching Buildplate`** (for the rare case you do enable support). Never `Everywhere` on these hollow parts — that is what filled the `outer_box` cavity.
3. **Support Z Distance → 0.4mm** (Top Distance `0.4`, Bottom Distance `0.2`). PETG needs double the PLA default or it welds.
4. **Support Pattern → `Zig Zag`; Support Wall Line Count → `0`; Support Density → `8 %`.** Grid plus a support wall is what made it a solid block.
5. **Support Distance Priority → `Z overrides X/Y`**, Support X/Y Distance `0.8`. Stops the outer ring of support welding to overhang edges.
6. **Top Layers → 5, Bottom Layers → 5, Infill Density → 25 % minimum.** Fixes the exposed-infill / pillowed internal surfaces (the lid recess failure).
7. **Wall Line Count → 5.** Straight from the v6.1 fit-test — 3 perimeters is why the small bosses came out weak.
8. **Fan Speed → 40 %, Initial Fan Speed → 0 %, Enable Bridge Settings ON with Bridge Fan Speed 100 %.** Clean overhangs without destroying PETG layer adhesion.
9. **Retraction Distance → 2.0mm @ 35 mm/s; Combing Mode → `Within Infill`; Travel Speed → 150 mm/s.** Kobra Neo is direct-drive — the 5–6mm advice online is for Bowden and will grind your filament.
10. **Enable Ironing ON** (Flow 8 %, Inset 0.35, Zig Zag) for `top_plate`, `esp32_pod_lid`, `base_plate` only — and **dry the PETG at 60–65 °C for 4–6 h** before the run. Half of "bad settings" is wet filament.

---

## 6. Known documentation drift (fix before the next print run)

- `print_batch/README_FOR_WORKSHOP.txt` is at **v6.1** and predates the **v7.2** change that made `top_plate` a PETG part and created `dot_insert` as the resin part. Its Batch-4 listing and its "the PETG copies are fit-test only" line are stale.
- `print_batch/Batch4_Resin/` still contains a pre-v7.2 `top_plate.stl`, and there is no `dot_insert.stl` in any batch folder. Regenerate the batch folders and the ZIP.
- The README's "Walls: 3 perimeters" contradicts the v6.1 fit-test finding that **5** is needed for the small bosses. Use 5.
- The README's "Layer height 0.2mm" for Batch 2 is fine for `base_plate`, but `mid_plate` and `top_plate` are better at 0.16 (§2.5, §2.6).

---

## Appendix — Braille geometry (carried over, for the presentation)

- **Dot size:** 1.5mm dome — inside the international standard range (1.44–1.60mm).
- **Pitch:** 4.8mm column spacing, 2.6mm row spacing. This is **jumbo braille**, used for learners and readers with reduced tactile sensitivity — a deliberate accessibility choice, not a compromise. (See §4 of the CAD audit for the full rationale.)
- **Travel height:** dots rise 0.8mm — comfortably readable.
- **Why this matters for printing:** the real braille features exist **only on the resin `dot_insert`**. On this printer, raised features under ~2.5mm print as mush — that is why all PETG parts use bold ≥3mm tactile shapes (the ^ chevron on the box front, the ⠿ marker on the pod lid) instead of braille.

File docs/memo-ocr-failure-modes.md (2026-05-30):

# Memo: Math OCR Failure Modes — pix2tex in the Braillix Pipeline

**Author:** Shaurya Verma (L4 Input Processor)  
**Date:** 2026-05-30  
**Audience:** Braillix backend + demo team

---

## Overview

pix2tex (LaTeX-OCR) uses a Vision Transformer (ViT) + GPT-2 decoder trained on
the im2latex dataset to convert images of mathematical equations to LaTeX strings.
It is the Phase 2 OCR engine in our pipeline. This memo documents its expected
accuracy, known failure modes, and what to show in the demo.

---

## Accuracy Expectations

| Input Type | Expected Accuracy | Notes |
|---|---|---|
| Clean printed math, white background | 85–92% | Best case — printed textbooks |
| Printed math, photographed (~300 DPI) | 65–80% | Typical phone photo, good lighting |
| Printed math, photographed (<150 DPI) | 40–60% | Low-res or far shot |
| Handwritten math | 20–40% | Not trained for handwriting |
| Mixed text + equations (inline) | 30–50% | pix2tex crops full images; struggles with inline |
| Multi-line stacked equations | 45–65% | Alignment matters; line breaks confuse decoder |

*Source: LaTeX-OCR GitHub benchmarks; entropy analysis paper (arxiv 2412.01221)*

---

## Top 7 Failure Modes (Ranked by Likelihood in Our Use Case)

| # | Failure Mode | Frequency | Root Cause | Mitigation |
|---|---|---|---|---|
| 1 | **Low-resolution photo** | Very High | Pixel aliasing confuses ViT patches | Enforce ≥150 DPI; provide capture guide to users |
| 2 | **Complex fractions** (`\frac{\frac{a}{b}}{c}`) | High | Nested tokens exceed model confidence | Pre-process to simplify; flag confidence < 0.7 |
| 3 | **Integral / summation with limits** | High | Long-range dependency in decoder | Out-of-distribution; fall back to manual entry |
| 4 | **Handwritten or mixed handwriting** | High | Training data is exclusively printed | Gate: reject if image has irregular stroke widths |
| 5 | **Mixed Hindi-English text** | Medium | Devanagari chars produce token errors | Crop equations from text blocks before OCR |
| 6 | **Matrix / tabular notation** | Medium | Multi-column layout breaks row tokenization | Flag for manual review; show raw image to student |
| 7 | **Greek letters in context** (`\alpha\beta`) | Medium | Confuses `\alpha` with `a`, `\beta` with `b` | Post-process: compare decoded LaTeX to known Greek Unicode range |

---

## Confidence Score Thresholds

pix2tex does not expose a direct confidence score, but the entropy of the output
token distribution is a usable proxy (per arxiv 2412.01221):

| Entropy Range | Reliability | Action |
|---|---|---|
| < 0.3 | High confidence | Auto-send to Braille translator |
| 0.3 – 0.6 | Medium confidence | Show preview to teacher for confirmation |
| > 0.6 | Low confidence | Flag with ⚠️, offer manual LaTeX entry |

Implementation note: We can approximate confidence by checking if the output
contains `\\` (line break in failed expressions), unmatched braces `{`, or
the string `???` which pix2tex emits for unrecognized tokens.

---

## Recommendations for Demo

**Use these input types — guaranteed to work:**

1. Simple polynomials: `x^2 + 3x + 2 = 0` — printed clearly, white paper
2. Linear equations: `2x + 5 = 11` — NCERT Class 7 style, large font
3. Pythagoras: `a^2 + b^2 = c^2` — visually simple, all ASCII math
4. Basic arithmetic: `\frac{3}{4} + \frac{1}{4} = 1` (simple fraction)

**Avoid in demo:**
- Matrices, integrals, summations with complex bounds
- Handwritten equations (reliability < 40%)
- Photos taken under poor/uneven lighting

**Camera setup recommendation:** Print equation on white A4 paper, photograph
from directly above at 30cm distance in daylight. Phone camera at ≥12MP will
give ~300 DPI at that distance — well above the reliability threshold.

---

## Phase 2 Upgrade: Nougat / Texify

For Phase 2, evaluate **Texify** (VikParuchuri) which is trained on a more diverse
web dataset and handles inline equations better than pix2tex. It uses the same
ViT+decoder architecture but has broader training coverage. Texify is also
open-source (MIT) and free to run locally.

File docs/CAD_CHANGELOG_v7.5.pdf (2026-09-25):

# CAD v7.5 - defect repair pass

Date: 2026-07-30 Trigger: the v7.3 pre-assembly audit found 8 blocking defects. None had been fixed. Scope: everything fixable without calipers. Four items remain blocked on measurement and are now tagged in-source with MEASURE (Mnn) pointing at docs/MEASUREMENTS_NEEDED.md.
Every part was re-rendered and checked for Volumes: 2 - meaning one connected solid. That check is what caught the floating cable hooks in v7.4 and the vanished nav caps before that; Simple: yes alone does not catch disconnected geometry.

## Side-by-side: what changed

# | File | Was | Now | Why

1 | mech_layout.scad | homing magnet declared twice, in two files, already drifted (cam r=17.35 vs plate y=20) | one shared block: homin g_mag_dia/thk/fit/r /angle | The sensor must sit under the magnet. Two copies guarantee they drift apart.
2 | braille_cam.scad | magnet_depth = 2.0 into a 2.0mm floor | 1.2 (3x1mm magnet), + assert | Pocket was a through-hole cratering tracks 2, 3 and 4. A foot crossing it jams.
3 | braille_cam.scad | comment claimed "8mm engagement" | corrected to 6mm, full z-stack failure documented | Stale comment hid a real showstopper.
4 | base_plate.scad | base_length = 56 | 58 | Left ear screw had a 0.35mm wall - breaks out. Also fixed standoffs overhanging by 1mm.
5 | base_plate.scad | spring_cavity() -22x16 through-window | deleted | Right motor screw (x=+9.5) opened into it -> one-screw motor. Cavity was v6.x legacy; springs moved to the top plate in v7.1.
6 | base_plate.scad | dia 4.3 clearance holes | dia 3.3 thread-forming pilots | A nut at x=+9.5 sits under the spinning cam. Screw now threads straight into the plate from below.
7 | base_plate.scad | hall pocket cut down from the top at (0,20) | cut up from the underside at (0, 17.35) | Old pocket lay entirely inside the cam pocket at the same depth - it removed nothing; the feature did not exist on the printed part.
8 | base_plate.scad | - | assert on sensor thickness | Fails loudly if the measured sensor won't fit, instead of printing a useless pocket.
9 | esp32_pod_params.sc ad | pod_length = 64 | 68 | Board overran the cavity by 1.75mm - would not go in. Bonus: pod is now a 68x68x58 cube matching a cell exactly.
10 | esp32_pod_params.sc ad | devkit_x_offset = 4 | -2 | Plug reach into the pod cut from 6.25mm to 2.25mm.
11 | esp32_pod_params.sc ad | usb_z = floor + strip_h + 1 | board_under_z - 1.0 | Arithmetic bug - ignored hdr_channel_depth. Hole sat ~2mm high; only 0.5mm overlapped the port.
12 | esp32_pod_params.sc ad | USB cutout 10x7 | 13x9 | A real cable's moulded body doesn't pass 10x7.

# | File | Was | Now | Why

13 | esp32_pod_params.sc ad | barrel_jack_x = -22 | -20 | Cradle overran the wall; lid couldn't close.
14 | esp32_pod_params.sc ad | lid_screw_x = 27.5 hard-coded | pod_int_length/2 -0.5 | See below - this one was created by fix #9.
15 | esp32_pod_lid.scad | 4 hard-coded dims matching the old pod | derived from pod_length/pod_width | Lengthening the pod would have silently desynced the lid.
16 | esp32_pod_lid.scad | - | assert on cradle vs wall | The overrun was invisible because all three jack dims are invented.
17 | outer_box.scad | muscle-board bosses always on | use_muscle_board_bo sses = false | dia 4x4mm bosses sit inside the ULN2003's footprint - board would perch 4mm up in a 16mm pocket.
18 | outer_box.scad, mid_plate.scad | motor numbers unmarked | tagged MEASURE (M1), (M2) | So the assumptions are findable rather than looking like facts.

## The defect that fix #9 *created*

Worth recording, because it's the same bug the codebase has now hit three times.
lid_screw_x = 27.5 was correct only while pod_int_length was 56: the inner wall sat at x=28, so a dia 5 boss at 27.5 spanned 25-30 and embedded 2mm into the wall.
Lengthening the pod moved that wall to x=30. The boss would then have spanned 27-32 and merely touched the wall at exactly one plane - a disconnected body in the STL, printing as a loose tower. That is precisely the failure the comment block above that line was written to describe after it happened in v6.1b.
It is now a formula tied to the wall, so it cannot drift again.
Pattern: hard-coded numbers that "happen to match" another dimension are the main source of defects in this project. Fixes #1, #14 and #15 are all the same cure.

## Verification

All parts re-rendered from source. Volumes: 2 = one connected solid:

Part | Simple | Volumes
outer_box | yes | 2
mid_plate | yes | 2
base_plate | yes | 2
top_plate | yes | 2
dot_insert | yes | 2
linkage | yes | 2
nav_cap | yes | 2
pogo_end_cap | yes | 2
esp32_pod_shell | yes | 2
esp32_pod_lid | yes | 2
braille_cam | yes | 2
Both new asserts were exercised - the cam and lid render clean, so the magnet pocket leaves enough floor and the cradle fits inside the wall.

## Still open - blocked on measurement

These are not fixable by guessing harder. Each depends on a physical number.

Defect | Needs | Consequence if ignored
Cam z-stack doesn't close: hub_h=4 into a 2mm gap | M2, M6, M7 | All six dots permanently ~2mm proud - every dot reads as "on"
Hall pocket depth is 1.6mm | M11b | Sensor may not fit; assert will catch it
Barrel jack cradle is 100% invented | M12-M16 | Jack unsupported, or lid won't close
ESP32 pin-row pitch: CAD says 38-pin, docs say 30-pin | M18, M21 | ESP32 cannot plug into the pod at all

The z-stack must be re-derived in one pass once M2/M6/M7 arrive - motor height -> base plate -> cam -> linkage length are a single chain, and patching them individually just relocates the error.

## Bill-of-materials correction

ELECTRONICS_BOM.md item 7 says buy a 3x2mm homing magnet. Buy 3x1mm.
The cam disc floor is 2.0mm. A 2mm magnet needs a 2mm pocket, which removes the entire floor. 1mm leaves 0.8mm behind and couples just as well, because the magnet still sits flush with the disc underside.

## What did NOT change, deliberately

### - 68x68mm cell shell, docking windows, magnet pockets, 4mm walls - already physically

fit-tested. Untouched.
- Teardrop magnet pockets - correct shape-based self-support. Keep.
- No sacrificial bridges re-added - removed in v7.4 for good reasons documented in outer_box.scad.
- Nothing in the resin plate-1 batch already ordered. All of v7.5's changes are in PETG parts not yet printed. Nothing in transit is affected.

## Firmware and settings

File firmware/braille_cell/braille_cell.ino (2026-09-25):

/*
 * Braillix — bare-motor letter test
 *
 * Type a letter (or a word) in the Serial Monitor and the cam turns to that
 * character's state. No linkages, no cell, no disc required: this proves the
 * ESP32, the ULN2003, the motor, the encoding and the homing path all work
 * before any of it is bolted to a mechanism.
 *
 * Board:     ESP32 Dev Module (30-pin, USB-C)
 * Library:   AccelStepper (Mike McCauley) — Library Manager
 * Serial:    115200 baud, "Newline" line ending
 *
 * Deliberately no WiFi and no OTA. secrets.h is not needed. The point of this
 * sketch is the shortest possible path to a turning motor.
 *
 * Wiring (identical to docs/BREADBOARD_STEP_BY_STEP.md):
 *   ULN2003 IN1 -> GPIO 18       ULN2003 (+) -> 5V rail (adapter)
 *   ULN2003 IN2 -> GPIO 19       ULN2003 (-) -> GND rail
 *   ULN2003 IN3 -> GPIO 21       Hall AO     -> GPIO 34
 *   ULN2003 IN4 -> GPIO 22       Hall VCC    -> 3V3, Hall GND -> GND
 *   ESP32 GND   -> GND rail  <-- the one wire that must not be missed
 */

#include <AccelStepper.h>
#include <WiFi.h>
#include <WebServer.h>
#include <BLEDevice.h>
#include <BLEServer.h>
#include <BLEUtils.h>
#include <BLE2902.h>

// --- BLUETOOTH LOW ENERGY -------------------------------------------------
// Nordic UART Service UUIDs. Not a standard, but the de-facto one every tool
// and library already knows, so a generic BLE terminal app can drive the cell
// too - useful for debugging without the simulator.
#define NUS_SERVICE "6E400001-B5A3-F393-E0A9-E50E24DCCA9E"
#define NUS_RX      "6E400002-B5A3-F393-E0A9-E50E24DCCA9E"   // browser -> board
#define NUS_TX      "6E400003-B5A3-F393-E0A9-E50E24DCCA9E"   // board -> browser
const char* BLE_NAME = "Braillix-Cell";

BLECharacteristic* bleTx = nullptr;
volatile bool bleConnected = false;
String bleLine;                      // commands arrive whole, but never assume it

// --- WIRELESS -------------------------------------------------------------
// The board makes its OWN network. No router, no lab wifi, no credentials to
// beg for, and it works in a room with no internet at all. The laptop joins
// this AP and loses its internet for the duration - which is fine, because the
// simulator is served from localhost.
//
// NOT a personal secret: this is a throwaway AP password for a demo device on
// a network with one client. Change it if you like; nothing else depends on it.
const char* AP_SSID = "Braillix-Cell";
const char* AP_PASS = "braillix2026";     // >= 8 chars or softAP() opens it wide
// WiFi is now OFF by default. It cannot be reached from a GitHub Pages page at
// all: that page is https, the board is plain http, and browsers block mixed
// content. BLE has no such problem, and it does not take the laptop off its own
// network the way joining the AP does. Turn this back on only for a localhost demo.
const bool  USE_WIFI = false;
const bool  USE_BLE  = true;

WebServer server(80);

#define IN1 18
#define IN2 19
#define IN3 21          // NOTE: GPIO21/22 are the default I2C pins. Fine now;
#define IN4 22          // must move before the MCP23017 goes in (multi-cell).
#define HALL_PIN 34

AccelStepper stepper(AccelStepper::HALF4WIRE, IN1, IN3, IN2, IN4);

// --- from sim/3d/braillix_params.json — keep these in step with the simulator ---
const int STEPS_PER_REV = 4096;   // 28BYJ-48 half-steps, 64:1 gearbox
const int STEPS_PER_POS = 64;     // one of 64 cam states
const int DWELL_OFFSET  = 32;     // land MID-dwell, not on a ramp edge
#define USE_GRAY_ORDER 1          // must match braille_cam.scad's use_gray_order

// bit = DOT_TO_BIT[dot]; dot 1->3, 2->2, 3->1, 4->4, 5->5, 6->0
const uint8_t DOT_TO_BIT[7] = {0, 3, 2, 1, 4, 5, 0};

// Grade-1 braille a-z, as dot lists. Same table as sim/3d/app.js:23.
const uint8_t LETTER_DOTS[26][6] PROGMEM = {
  {1,0,0,0,0,0}, {1,2,0,0,0,0}, {1,4,0,0,0,0}, {1,4,5,0,0,0}, {1,5,0,0,0,0},
  {1,2,4,0,0,0}, {1,2,4,5,0,0}, {1,2,5,0,0,0}, {2,4,0,0,0,0}, {2,4,5,0,0,0},
  {1,3,0,0,0,0}, {1,2,3,0,0,0}, {1,3,4,0,0,0}, {1,3,4,5,0,0}, {1,3,5,0,0,0},
  {1,2,3,4,0,0}, {1,2,3,4,5,0}, {1,2,3,5,0,0}, {2,3,4,0,0,0}, {2,3,4,5,0,0},
  {1,3,6,0,0,0}, {1,2,3,6,0,0}, {2,4,5,6,0,0}, {1,3,4,6,0,0}, {1,3,4,5,6,0},
  {1,3,5,6,0,0}
};

const int HALL_THRESHOLD = 500;   // analogRead below this = magnet present
bool homed = false;

// Tunable live over serial (!speed, !gap). A one-state move is only 64 steps, so
// it is ACCELERATION-limited, not speed-limited: at accel 500 the motor needs 490
// steps just to reach 700, and never gets past 179 steps/s on a single letter.
// Raising accel shortens short moves; raising vmax only helps long ones.
int  vmax  = 1000;   // half-steps/s. 28BYJ-48 torque falls off hard past ~1200.
int  accel = 2000;   // half-steps/s^2
int  gapMs = 250;    // hold time between characters of a typed word

// --- encoding -------------------------------------------------------------

int cellToState(char c) {
  if (c == ' ') return 0;
  if (c < 'a' || c > 'z') return -1;
  int state = 0;
  for (int i = 0; i < 6; i++) {
    uint8_t dot = pgm_read_byte(&LETTER_DOTS[c - 'a'][i]);
    if (dot == 0) break;
    state |= (1 << DOT_TO_BIT[dot]);
  }
  return state;
}

// v8.2 GRAY ORDER. The cam carries pattern gray(i) = i ^ (i>>1) at slice i, so
// to show pattern P we must rotate to the slice whose Gray value IS P — that is
// grayToBinary(P), not P. Get this wrong and every letter shows a different one.
// Must stay in step with use_gray_order in cad/scad/braille_cam.scad.
int grayToBinary(int g) {
  int b = g;
  while (g >>= 1) b ^= g;
  return b;
}

int stateToStep(int state) {
  int slice = USE_GRAY_ORDER ? grayToBinary(state) : state;
  return slice * STEPS_PER_POS + DWELL_OFFSET;
}

// Shortest path: wrap the target to the nearest equivalent of where we are.
// Matches the simulator's gotoIndex(). Without this, 63 -> 0 spins 354 degrees
// the wrong way instead of stepping 5.6 degrees back.
long shortestTarget(long current, int wantStep) {
  long diff = ((wantStep - current) % STEPS_PER_REV + STEPS_PER_REV * 3 / 2)
              % STEPS_PER_REV - STEPS_PER_REV / 2;
  return current + diff;
}

// --- motion ---------------------------------------------------------------

void runToTarget() {
  while (stepper.distanceToGo() != 0) stepper.run();
}

void releaseCoils() {                 // stop cooking the motor while idle
  digitalWrite(IN1, LOW); digitalWrite(IN2, LOW);
  digitalWrite(IN3, LOW); digitalWrite(IN4, LOW);
}

// Move to one of the 64 cam states. Split out of showChar() so the browser can
// drive a state directly over Web Serial: the simulator already expands text into
// cells (including the capital/number indicators this table knows nothing about),
// so the encoding lives in ONE place and the firmware just follows.
void showState(int state) {
  long from   = stepper.currentPosition();
  long target = shortestTarget(from, stateToStep(state));
  long delta  = target - from;

  Serial.printf("state %2d  step %4d  move %+5ld (%s)  %.1f deg",
                state, stateToStep(state), delta,
                delta >= 0 ? "CW " : "CCW", delta * 360.0 / STEPS_PER_REV);

  stepper.moveTo(target);
  runToTarget();
  stepper.setCurrentPosition(((target % STEPS_PER_REV) + STEPS_PER_REV) % STEPS_PER_REV);
  releaseCoils();
}

void showChar(char c) {
  int state = cellToState(c);
  if (state < 0) { Serial.printf("  skip '%c' (a-z and space only)", c); return; }

  Serial.printf("  '%c'  dots ", c == ' ' ? '_' : c);
  if (c == ' ') Serial.print("(none)  ");
  else {
    for (int i = 0; i < 6; i++) {
      uint8_t d = pgm_read_byte(&LETTER_DOTS[c - 'a'][i]);
      if (d == 0) break;
      Serial.printf("%d", d);
    }
    Serial.print("  ");
  }
  showState(state);
}

// Look for the homing magnet. There is no cam disc yet, so this MUST NOT hang.
void tryHome() {
  Serial.println("Homing: looking for the magnet (one revolution max)...");
  stepper.setCurrentPosition(0);
  stepper.moveTo(STEPS_PER_REV);
  int best = 4095; long bestAt = 0;
  while (stepper.distanceToGo() != 0) {
    stepper.run();
    int v = analogRead(HALL_PIN);
    if (v < best) { best = v; bestAt = stepper.currentPosition(); }
  }
  releaseCoils();
  if (best < HALL_THRESHOLD) {
    Serial.printf("  magnet found at step %ld (reading %d). Zero set there.\n", bestAt, best);
    stepper.setCurrentPosition(((stepper.currentPosition() - bestAt) % STEPS_PER_REV
                                + STEPS_PER_REV) % STEPS_PER_REV);
    homed = true;
  } else {
    Serial.printf("  no magnet (best reading %d, need < %d).\n", best, HALL_THRESHOLD);
    Serial.println("  EXPECTED right now — there is no disc on the shaft yet.");
    Serial.println("  Treating the current position as zero. Motion still works.");
    stepper.setCurrentPosition(0);
    homed = false;
  }
}

// One entry point for a command, whatever carried it here. Serial, HTTP and BLE
// all funnel through this, so the three transports can never drift apart.
void handleLine(String line, bool echo);

// --- wireless API ---------------------------------------------------------
// Every handler BLOCKS until the motor has arrived, so the HTTP response is the
// "done" signal - same contract the serial prompt gives, so the simulator syncs
// against either transport without knowing which it is talking to.
void cors() { server.sendHeader("Access-Control-Allow-Origin", "*"); }

void handleState() {
  cors();
  if (!server.hasArg("v")) { server.send(400, "text/plain", "need ?v=0-63"); return; }
  int st = server.arg("v").toInt();
  if (st < 0 || st > 63) { server.send(400, "text/plain", "state must be 0-63"); return; }
  showState(st);
  server.send(200, "text/plain", "ok");
}

void handleSpeed() {
  cors();
  int v = server.arg("v").toInt(), a = server.arg("a").toInt();
  if (v > 0 && a > 0) {
    vmax = v; accel = a;
    stepper.setMaxSpeed(vmax); stepper.setAcceleration(accel);
  }
  server.send(200, "text/plain", "ok");
}

void handlePing()  { cors(); server.send(200, "text/plain", homed ? "homed" : "not-homed"); }
void handleHome()  { cors(); tryHome(); server.send(200, "text/plain", "ok"); }

void startWifi() {
  WiFi.mode(WIFI_AP);
  WiFi.softAP(AP_SSID, AP_PASS);
  server.on("/s", handleState);
  server.on("/speed", handleSpeed);
  server.on("/ping", handlePing);
  server.on("/home", handleHome);
  // the browser preflights any cross-origin GET it considers non-simple
  server.onNotFound([]() { cors(); server.send(204); });
  server.begin();
  Serial.println();
  Serial.printf("WiFi AP up:  SSID \"%s\"  pass \"%s\"\n", AP_SSID, AP_PASS);
  Serial.printf("  join it, then point the simulator at  http://%s\n",
                WiFi.softAPIP().toString().c_str());
}

class BleServerCB : public BLEServerCallbacks {
  void onConnect(BLEServer* s) override { bleConnected = true;  Serial.println("\nBLE connected"); }
  void onDisconnect(BLEServer* s) override {
    bleConnected = false;
    Serial.println("\nBLE disconnected");
    BLEDevice::startAdvertising();      // otherwise it is invisible after one use
  }
};

class BleRxCB : public BLECharacteristicCallbacks {
  void onWrite(BLECharacteristic* c) override {
    String v = String(c->getValue().c_str());
    v.trim();
    if (!v.length()) return;
    handleLine(v, false);
    // showState() has already returned, so the motor has ARRIVED. That is what
    // the simulator waits on before advancing to the next cell.
    if (bleTx) { bleTx->setValue("ok"); bleTx->notify(); }
  }
};

void startBle() {
  BLEDevice::init(BLE_NAME);
  BLEServer* srv = BLEDevice::createServer();
  srv->setCallbacks(new BleServerCB());
  BLEService* svc = srv->createService(NUS_SERVICE);

  bleTx = svc->createCharacteristic(NUS_TX, BLECharacteristic::PROPERTY_NOTIFY);
  bleTx->addDescriptor(new BLE2902());

  BLECharacteristic* rx = svc->createCharacteristic(
      NUS_RX, BLECharacteristic::PROPERTY_WRITE | BLECharacteristic::PROPERTY_WRITE_NR);
  rx->setCallbacks(new BleRxCB());

  svc->start();
  BLEAdvertising* adv = BLEDevice::getAdvertising();
  adv->addServiceUUID(NUS_SERVICE);      // the browser filters on this; without
  adv->setScanResponse(true);            // it the device never appears in the picker
  BLEDevice::startAdvertising();
  Serial.printf("\nBLE up: look for \"%s\" in the simulator\n", BLE_NAME);
}

void help() {
  Serial.println();
  Serial.println("Type a letter or a word, then Enter.  Examples:  a    hello    cab");
  Serial.println("Commands:  !s N    go to cam state N (0-63) - the web simulator uses this");
  Serial.println("           !home   re-run homing");
  Serial.println("           !zero   call this position step 0");
  Serial.println("           !hall   print the hall reading");
  Serial.println("           !spin   one full revolution, to eyeball direction");
  Serial.println("           !speed V A   set max speed and acceleration");
  Serial.println("           !gap MS      pause between letters of a word");
  Serial.println("           !help   this list");
  Serial.println();
}

void setup() {
  Serial.begin(115200);
  delay(600);
  Serial.println("\n=== Braillix bare-motor letter test ===");
  Serial.printf("%d steps/rev, %d steps/state, +%d mid-dwell offset\n",
                STEPS_PER_REV, STEPS_PER_POS, DWELL_OFFSET);

  pinMode(HALL_PIN, INPUT);
  stepper.setMaxSpeed(vmax);     // must ramp; commanding full speed cold = stall
  stepper.setAcceleration(accel);

  tryHome();
  if (USE_WIFI) startWifi();
  if (USE_BLE)  startBle();
  help();
  Serial.print("> ");
}

void handleLine(String line, bool echo) {
  line.trim();
  line.toLowerCase();
  if (line.length() == 0) return;

  if (line.startsWith("!")) {
    if      (line == "!home") tryHome();
    else if (line == "!zero") { stepper.setCurrentPosition(0); Serial.println("  zero set."); }
    else if (line == "!hall") Serial.printf("  hall = %d\n", analogRead(HALL_PIN));
    else if (line.startsWith("!speed")) {
      int v, a;
      if (sscanf(line.c_str(), "!speed %d %d", &v, &a) == 2 && v > 0 && a > 0) {
        vmax = v; accel = a;
        stepper.setMaxSpeed(vmax); stepper.setAcceleration(accel);
        Serial.printf("  vmax %d (%.1f RPM), accel %d\n", vmax, vmax * 60.0 / STEPS_PER_REV, accel);
        if (vmax > 1200) Serial.println("  WARNING: past ~1200 the 28BYJ-48 will start skipping steps.");
      } else Serial.println("  usage: !speed <maxspeed> <accel>   e.g. !speed 1000 2000");
    }
    else if (line.startsWith("!gap")) {
      int g;
      if (sscanf(line.c_str(), "!gap %d", &g) == 1 && g >= 0) { gapMs = g; Serial.printf("  gap %d ms\n", gapMs); }
      else Serial.println("  usage: !gap <milliseconds>");
    }
    else if (line.startsWith("!s ")) {
      int st;
      if (sscanf(line.c_str(), "!s %d", &st) == 1 && st >= 0 && st < 64) showState(st);
      else Serial.println("  usage: !s <0-63>   (cam state, used by the web simulator)");
    }
    else if (line == "!spin") {
      Serial.println("  one revolution...");
      stepper.moveTo(stepper.currentPosition() + STEPS_PER_REV);
      runToTarget(); releaseCoils();
      stepper.setCurrentPosition(stepper.currentPosition() % STEPS_PER_REV);
      Serial.println("  done.");
    }
    else help();
  } else {
    for (unsigned i = 0; i < line.length(); i++) {
      showChar(line[i]);
      delay(gapMs);               // hold each letter long enough to see it
    }
  }
}

void loop() {
  if (USE_WIFI) server.handleClient();
  if (!Serial.available()) return;
  String line = Serial.readStringUntil('\n');
  handleLine(line, true);
  Serial.print("> ");
}

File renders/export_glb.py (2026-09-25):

#!/usr/bin/env python
"""
export_glb.py — turn the Braillix STLs into one web-ready model for the 3D simulator.

    "C:\\Program Files\\Blender Foundation\\Blender 5.1\\blender.exe" ^
        --background --factory-startup --python renders/export_glb.py

Output: sim/3d/braillix.glb

WHY BLENDER IS ONLY THE ASSET PIPELINE HERE
The simulator needs orbit/pan/zoom, an X-ray toggle and a kinematics toggle. Blender
renders a fixed video and cannot do any of that, so the interactive part is a Three.js
app. Blender's job is just to assemble the STLs onto the real z-stack, name the parts,
and emit a single GLB the browser can load.

UNITS ARE MILLIMETRES. 1 Blender unit = 1 mm, deliberately: every number in
sim/braillix_params.json is in mm, so the web app can use them directly with no
conversion. Nothing is rendered here, so the usual "work in metres" advice does not
apply.

OBJECT NAMES ARE AN API. The web app looks parts up by name — outer_box, top_plate,
dot_insert, base_plate, cam, linkage_1..6, motor_body, motor_shaft,
motor_ear_l, motor_ear_r. Renaming anything here breaks sim/3d/app.js.
"""
import bpy
import json
import math
import os
import sys

ROOT = r"D:\TIET\Capstone"
STL = os.path.join(ROOT, "cad", "stl")
OUT_DIR = os.path.join(ROOT, "sim", "3d")
OUT = os.path.join(OUT_DIR, "braillix.glb")

P = json.load(open(os.path.join(ROOT, "sim", "braillix_params.json")))
CAM_FLAT = P["stack"]["cam_flat_z"]          # 45.0

# name -> (z offset, hex colour, alpha, metallic, roughness)
# Z values are the NOMINAL INTENDED stack. Two 2mm errors in the real stack are still
# being re-derived (see .ai-sync/handoff.md); this model shows design intent and the
# narration says so.
# Z offsets are DERIVED, never typed. v8.5 dropped the whole tower 14mm (motor
# straight onto the box floor, mid-plate deleted) and every literal here would
# have been silently wrong — which is exactly the failure this project keeps
# hitting. Read the stack from the same JSON the simulator reads.
with open(os.path.join(ROOT, "sim", "braillix_params.json"), encoding="utf-8") as _f:
    _P = json.load(_f)
CAM_FLAT_Z = _P["stack"]["cam_flat_z"]          # 31.0  cam surface, dot DOWN
PLATE_UNDER_Z = _P["stack"]["plate_under_z"]    # 40.0  top plate underside
DISC_THK = _P["cam"]["disk_base_thickness"]     # 2.0
BASE_THK, CAM_POCKET = 5.0, 3.0                 # base_plate.scad:34,39

BASE_PLATE_TOP = CAM_FLAT_Z + CAM_POCKET - DISC_THK   # 34.5
BASE_PLATE_Z = BASE_PLATE_TOP - BASE_THK              # 29.5, v8.8
CAM_Z = BASE_PLATE_TOP - CAM_POCKET                   # 31.5 disc underside

PARTS = {
    "outer_box":   (0.0,            "5A6B7C", 1.00, 0.05, 0.75),
    "base_plate":  (BASE_PLATE_Z,   "6E6E6E", 1.00, 0.10, 0.85),
    "braille_cam": (CAM_Z,          "E94560", 1.00, 0.35, 0.35),
    "top_plate":   (PLATE_UNDER_Z,  "EDE6D6", 1.00, 0.05, 0.70),
    "dot_insert":  (PLATE_UNDER_Z,  "FAFAFA", 1.00, 0.05, 0.35),
    # linkage_comb.scad measures rest_z RELATIVE to cam flat, so the STL exports
    # flat for printing and is lifted by cam_flat_z here.
    "linkage_comb": (CAM_FLAT_Z,    "9AA3B2", 1.00, 0.05, 0.60),
}
# mid_plate is GONE as of 2026-08-26 (dc42248). The motor stands on a cup in the
# box floor; the plate and its ledge were the 4mm that stopped the cam seating.
RENAME = {"braille_cam": "cam", "linkage_comb": "comb"}
LINKAGE_MAT = ("C8CDD4", 1.00, 0.90, 0.25)   # shiny metal, as specified

# 28BYJ-48. M1/M2/M6 are Codex's researched values (docs/MEASUREMENT_RESEARCH.md);
# M5 and the ear envelope are still unverified, so the motor is indicative only.
MOTOR = dict(dia=28.0, height=19.0, x_offset=-8.0,
             shaft_dia=5.0, shaft_len=9.5, ear_span=35.0, ear_w=7.0, ear_t=1.0)


def rgba(hx, a=1.0):
    return (*(int(hx[i:i + 2], 16) / 255 for i in (0, 2, 4)), a)


def material(name, hx, alpha=1.0, metal=0.0, rough=0.5):
    m = bpy.data.materials.new(name)
    m.use_nodes = True
    b = m.node_tree.nodes["Principled BSDF"]
    b.inputs["Base Color"].default_value = rgba(hx)
    b.inputs["Metallic"].default_value = metal
    b.inputs["Roughness"].default_value = rough
    if alpha < 1.0:
        b.inputs["Alpha"].default_value = alpha
        m.blend_method = 'BLEND'
    return m


def import_stl(path, name):
    """Import and FAIL LOUDLY if missing.

    renders/build_assembly_scene.py silently skipped absent STLs, which is how it kept
    'working' long after braille_cam2.stl and linkage_comb.stl ceased to exist.
    """
    if not os.path.exists(path):
        sys.exit(f"MISSING STL: {path}\n"
                 f"  For linkage_asm_*.stl run:\n"
                 f"  for d in 1..6: openscad -D dot=$d -o cad/stl/linkage_asm_$d.stl "
                 f"cad/scad/export_linkage_assembly.scad")
    before = set(bpy.data.objects)
    bpy.ops.wm.stl_import(filepath=path, global_scale=1.0)   # keep millimetres
    new = set(bpy.data.objects) - before
    if len(new) != 1:
        sys.exit(f"expected 1 object from {path}, got {len(new)}")
    obj = new.pop()
    obj.name = name
    obj.data.name = name + "_mesh"
    return obj


def add_motor():
    """Indicative 28BYJ-48 so the X-ray view shows what drives the cam.

    There is no motor STL in the repo. renders/add_hardware_models.py builds one, but
    against the stale v5 z-stack, so the geometry idea is reused and the heights are
    re-derived from BASE_PLATE_Z here.
    """
    made = []
    body_mat = material("mat_motor", "9BA3AA", 1.0, 0.85, 0.30)
    shaft_mat = material("mat_shaft", "D8DDE2", 1.0, 0.95, 0.15)
    cx, z_top = MOTOR["x_offset"], BASE_PLATE_Z

    bpy.ops.mesh.primitive_cylinder_add(
        radius=MOTOR["dia"] / 2, depth=MOTOR["height"], vertices=48,
        location=(cx, 0, z_top - MOTOR["height"] / 2))
    b = bpy.context.object
    b.name = "motor_body"
    b.data.materials.append(body_mat)
    made.append(b)

    # shaft rises from the motor face into the cam bore (x=0 — NOT the body centre;
    # the 28BYJ-48 shaft is offset ~8mm, which is why the body sits at x=-8)
    bpy.ops.mesh.primitive_cylinder_add(
        radius=MOTOR["shaft_dia"] / 2, depth=MOTOR["shaft_len"], vertices=24,
        location=(0, 0, z_top + MOTOR["shaft_len"] / 2))
    s = bpy.context.object
    s.name = "motor_shaft"
    s.data.materials.append(shaft_mat)
    made.append(s)

    for sign, nm in ((-1, "motor_ear_l"), (1, "motor_ear_r")):
        bpy.ops.mesh.primitive_cube_add(
            size=1, location=(cx + sign * MOTOR["ear_span"] / 2, 0,
                              z_top - MOTOR["ear_t"] / 2))
        e = bpy.context.object
        e.name = nm
        e.scale = (MOTOR["ear_w"], MOTOR["ear_w"], MOTOR["ear_t"])
        e.data.materials.append(body_mat)
        made.append(e)
    return made
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

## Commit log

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2026-05-06 Audit redesign v4.0: fix 7 critical failures + add ESP32 pod
    - outer_box v4.0: elec_pocket 9→16mm, shell 50→57/60→68mm, mid-plate+collar,
    wire gutters, pogo recess, magnetic snap (no screws)
    - base_plate v2.2: motor body offset -8mm from shaft, widen to 56mm
    - linkage v3.0: inline feet at Y=0 (fixes Braille scrambling), dot 1/4 gap 2.0mm safe
    - top_plate v3.0: resize 52×60mm, round holes, spring pockets
    - braille_cam2 v2: hub inverts below disc, top clear
    - NEW: braille_cap (bearing ball cups), esp32_pod (74×38×58mm), linkage_comb
    (6-slit guide), pogo_end_cap (TPU cover)
    - All 9 STLs manifold ✓
    - Blender: Final + Exploded assemblies updated, shade flat, materials assigned
    - CH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
    [base_plate.scad, base_plate.stl, braille_cam2.scad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]
2026-05-06 fixed issues with joined mid plate and weird combs and few other changes
    [base_plate.stl, braille_cap.scad, braillix_assembly.blend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]
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2026-08-05 cad: archive third-party component models (KiCad, CC-BY-SA)
    TO-92, 1x15 pin socket and DIP-16 match our parts exactly; the barrel jack
    is a PCB-mount horizontal and ours is an inline pigtail, so it is reference
    only. Both STEP and WRL kept - STEP for CAD work, WRL as the route into
    Blender if we ever want them in the simulator.
    Licence is share-alike, so any derived mesh stays encumbered; README records
    that. Espressif's own module STEP was skipped: their repo carries no licence
    file at all. The two models actually worth having are on Sketchfab and need
    an account to download.
    [BarrelJack_CUI_PJ-063AH_Horizontal.step, DIP-16_W7.62mm.step, PinSocket_1x15_P2.54mm_Vertical.step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]
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2026-08-05 sim: populate the boards, add the loom, fix the dock magnets
    Magnets were wrong twice over: buried mid-wall and lying on their side.
    esp32_pod_shell.scad:52 cuts the pocket from the OUTER dock face inward, so
    the disc sits flush with the face, axis along X. Adds the cell's mating pair
    too, which were missing entirely.
    Boards now carry what is actually on them: the ULN2003 as a real DIP-16, the
    four coil LEDs with their series resistors, JST motor socket, IN1-4 and power
    headers, jumper and bulk cap; on the ESP32 the AMS1117, CH340C, crystal, BOOT
    and EN buttons, power LEDs and a scatter of 0805 passives.
    Wiring is drawn as swept tubes along Catmull-Rom curves so the jumpers sag
    like real D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
    [electronics.js]
2026-08-05 sim: real motor mesh, and a loom that respects the pogo interface
    Wiring was wrong in the way that mattered most: jumpers ran straight from
    the pod through the wall into the cell, which makes the pogo pins
    decorative. DEMO_VS_PRODUCT.md:130 is explicit - the four pogo contacts
    carry 5V, GND, SDA and SCL, and nothing else crosses. Each cell drives its
    own motor locally, which is the reason adding a cell costs no wiring.
    So the loom is now two separate harnesses. Inside the pod: DevKit header to
    the four pins. Inside the cell: pads to the driver, driver to the motor out
    through the mid-plate notch, hall sensor back to the pocket. Every run ends
    on an actual header or pad instead of in mid-air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
    [esp32_pod_lid.stl, esp32_pod_shell.stl]
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2026-08-05 sim: land every wire on a real pin, and put the hall sensor in its pocket
    The hall sensor was drawn 3.1mm tall standing at z=45, which put it inside
    the cam disc. base_plate.scad:98-106 says the pocket is 4.1 x 3.1 x 1.6 HIGH,
    buried under the cam pocket floor with 0.4mm of plate between, so the body
    belongs at 41.0..42.6. Fixed, and verified clear of the cam.
    Wires ended in mid-air because SDA, SCL and IN1-4 have nothing on a ULN2003
    to connect to. Added the empty MCP23017 footprint they actually go to in the
    multi-cell design; 5V and GND now land on the driver's own power header and
    the hall legs run to the expander. Motor run re-routed through the +X notch
    and held below z=41 so it stops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
    [electronics.js]
2026-08-05 sim: tidy the loom and fix the pogo pin geometry
    Iterated against actual screenshots rather than bounding boxes, which is how
    this should have been done from the start. Three real faults:
    The motor 5-core looped out into open space and doubled back before reaching
    the can. Rerouted short: socket, +X notch, straight across, onto the near
    face of the can.
    The pod's four wires bowed up through the middle of the cavity like a
    skipping rope - sparse control points let Catmull-Rom overshoot badly. They
    now hug the floor and climb the +X/+Y corner, and they end on the pins
    rather than 1.5mm short of them.
    Pogo pins rendered as flat discs: cyl() already sets rotation.x, and the
    helper then set ro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
    [electronics.js]
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2026-08-19 firmware: bare-motor letter test, serial driven
    Shortest path to a turning motor: no WiFi, no OTA, no secrets.h. Type a
    letter in the Serial Monitor and the cam turns to that character's state.
    Carries two things the old breadboard sketch does not: the +32 mid-dwell
    offset, so a state lands on flat cam rather than a ramp edge, and
    shortest-path rotation matching the simulator (verified across all 4096
    transitions, worst case 180 degrees rather than 354).
    Homing tolerates having no magnet, which is the case until a disc is on
    the shaft, and coils are released after each move.
    [braille_cell.ino]
2026-08-19 firmware: tune speed live from serial
    A one-state move is 64 steps, so it is acceleration-limited, not speed-limited:
    at accel 500 the motor needs 490 steps to reach 700 half-steps/s and never gets
    past 179 on a single letter. Raising acceleration is what shortens letter moves;
    raising max speed only helps the long ones.
    Defaults now 1000/2000 (was 700/500), which takes a single letter from 0.72s to
    0.36s, and !speed / !gap allow tuning by ear without a recompile.
    [braille_cell.ino]
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2026-08-23 sim+firmware: Bluetooth transport, so GitHub Pages can drive the cell
    WiFi could never work from the published site. That page is https, the board
    is plain http, and browsers block mixed content outright - no flag, no
    override. Joining the board's access point also took the laptop off its own
    network, which was a poor trade for a demo.
    BLE has neither problem. It is not fetch, so mixed content does not apply, and
    it runs alongside WiFi rather than replacing it. Bandwidth is a non-issue at
    ~8 bytes per letter against 7.5-50ms connection intervals.
    Uses the Nordic UART UUIDs, so a generic BLE terminal can drive the cell too
    when the simulator is not involved. The board notifies after showSta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
    [braille_cell.ino]
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2026-08-24 cad: square comb with orientation mark, and fix the cam shaft bore
    COMB. Square 48x48 so it drops in one way up and reads by hand. Rests on the
    base-plate face outside the cam pocket; a spigot under the middle drops into
    that pocket to centre it and four pegs at r=24.7 stop it turning. The middle is
    relieved so nothing touches the rotating cam. Top-left corner is chamfered and
    carries a raised triangle - every other corner is square, so it cannot be fitted
    the wrong way round. Pockets stay closed on all four sides.
    CAM BORE. The Double-D cut used cube(center=true) inside a translate, so it was
    centred on the translated origin: the cube spanned z=-4.5..4.5 while the cylinder
    spanned 0..9, an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
    [braille_cam.scad, braille_cam.stl, linkage_comb.scad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]
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2026-08-25 cam: Gray order, and the comb pegs it was missing
    CAM. Slice i now carries pattern gray(i) = i XOR (i>>1) rather than pattern i,
    so consecutive slices differ in exactly one bit and exactly one dot moves per
    step instead of up to six. Typing 'hello world' drops from 359 individual dot
    movements to 171, and peak torque falls about 6x because the motor lifts one dot
    at a time - which matters with one motor.
    This does NOT buy ramp room, despite my earlier claim. A state's angle is the
    CENTRE of its slice and the foot must be flat there, so a ramp always has one
    slice minus the foot to finish in however long the track then holds its value.
    Ramp room comes from radius, foot width, lift and ramp f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
    [base_plate.scad, base_plate.stl, braille_cam.scad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]
2026-08-25 sim: rebuild the GLB on the v8.2 cam, and add the linkage comb
    braillix.glb was 24 days old. braille_cam.stl and base_plate.stl were
    regenerated today, so the simulator was applying v8.2's Gray-order lookup to a
    binary-ordered cam mesh - the arithmetic was right and the geometry underneath
    it was not. Rebuilt: 17 objects, 47,968 polys.
    Adds linkage_comb, which was not in the pipeline at all. Its rest_z is measured
    RELATIVE to cam flat, so the STL exports flat for printing and needs lifting by
    45; its base then lands on the base-plate top at 46, which is what it rests on.
    Verified in the scene.
    extract_params.py could no longer read the stack: v8.2 made cam_flat_z and
    friends '45.0 + stack_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
    [export_glb.py]
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2026-08-25 docs: render the mechanism for the README, and draw the tree
    Replaces the ASCII linkage sketch with two renders built from the real geometry,
    not drawn by hand. renders/readme_mechanism.scad assembles the cam, the six
    linkages in their true positions, the comb and the top plate, using the same
    transform as export_linkage_assembly.scad. One linkage is raised by pin_lift and
    coloured, so the picture shows what the mechanism actually does: a foot standing
    on a high section of its track, and that dot proud of the reading surface.
    The enclosure is ghosted rather than hidden, so the dome is visible through it.
    The scene must be rendered in preview - CGAL discards alpha and the box comes out
    solid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
    [readme_mechanism.scad]
2026-08-25 docs: opaque reading surface, and fix the resin tile height
    The resin tile was drawn 0.8mm high. insert_h is defined as the reading-surface
    height above the plate underside, so the tile belongs AT plate_under_y; the extra
    (4 - 3.2) put its top face level with the plate rim rather than inside the finger
    recess, and hid the very thing the picture is for.
    The tile is now opaque, which is what makes the point readable: five dots sit
    flush and show only as holes, and the sixth stands proud. The comb is left out of
    these two views so the cam reads as solid and its track profile stays visible.
    [readme_mechanism.scad]
2026-08-25 cad+sim: regenerate every stale STL and rebuild both GLBs
    Audited all 34 STLs against their sources. Eleven single parts were built
    before the v8.2 changes and ALL of them came out different when re-run:
    outer_box, mid_plate, top_plate, dot_insert, linkage_comb, both pod halves,
    braille_cap, nav_cap, linkage, pogo_end_cap - plus the six linkage assemblies,
    whose sources moved on 08-25 while the STLs sat at 08-01.
    So the GLB rebuilt in the previous commit was still wrong: it had a fresh cam
    but stale walls, plates and comb. Both GLBs now come from current geometry.
    UI, from testing feedback:
    - the comb joins the X-ray set; it was the one printed part staying solid
    - Electronics no longer fo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
    [braille_cap.stl, dot_insert.stl, esp32_pod_lid.stl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]
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2026-08-25 cad: comb corner scallops, and standardise the pod on M2.5
    COMB. The four base-plate standoffs pass through the comb's corners. At (26, 21)
    with Ø6 a standoff reaches inward to x=23 while the comb runs to x=24, so a square
    corner fouls all four - Mridul spotted it. Scalloped with 0.4mm/side clearance,
    plus an assert that a scallop never reaches a foot pocket. Shrinking the comb
    instead is not an option: below 46mm across it falls into the Ø46 cam pocket it is
    supposed to rest beside.
    POD. M2 -> M2.5 on the lid, as requested in .ai-sync/handoff.md item 4 and
    BUILD_PACK 7.3, so the project buys one structural insert size. The condition
    attached to that request was 'only if the pod is not ye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
    [esp32_pod_lid.stl, esp32_pod_params.scad, esp32_pod_shell.stl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]
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2026-08-26 cad: motor cup in the box; the mid-plate and its ledge are gone
    THE 4MM. The cam hub is a 4mm tube under the disc and it can only reach the TOP
    of the motor's own 2mm shaft boss, never the mounting face. With the motor
    standing on a 2mm mid-plate resting on a 2mm ledge, the hub finished 4mm short and
    the cam could not seat at all - which is what Mridul hit in his hands.
    Shelf 2 + ledge 2 = exactly the 4mm needed. Both deleted. The motor now sits on a
    cup moulded into the box floor:
    floor 0.0 .. 4.0
    elec bay 4.0 .. 18.0 unchanged, still 14mm
    motor can 18.0 .. 37.0 rests on the cup seat at 18.0
    shaft boss 37.0 .. 39.0
    cam hub 39.0 .. 43.0 lands e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
    [base_plate.scad, mid_plate.scad, motor_spec.scad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]
2026-08-26 cad: motor onto the box floor, whole stack down 14mm
    Mridul's call, and correct: the motor was the only thing setting the height, and
    the 14mm electronics bay under it only existed because the driver board lay flat.
    With the board standing on edge against the +X wall that floor is free, so the
    motor drops onto it and everything above translates down with it.
    motor can 4.0 .. 23.0
    shaft boss 23.0 .. 25.0
    cam hub 25.0 .. 29.0
    cam disc 29.0 .. 31.0 cam_flat_z, was 45
    base plate 27.0 .. 32.0
    standoffs 32.0 .. 40.0
    top plate 40.0 .. 44.0 shell_height, was 58
    CELL AND POD BOTH 58 -> 44mm, a quarter shorter. The pod wa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
    [base_plate.stl, braille_cam.stl, dock_interface.scad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]
2026-08-31 sim: follow v8.5 - motor on the box floor, whole tower down 14mm
    The mid-plate and its 2mm ledge are gone (dc42248); the motor now stands on a
    cup in the outer box floor and everything above it dropped 14mm. cam_flat_z
    45 -> 31, plate_under_z 54 -> 40, shell_height 58 -> 44. Both GLBs were built
    against the old stack.
    export_glb.py had every z offset typed in as a literal, so it rebuilt happily
    and silently wrong. Offsets are now DERIVED from braillix_params.json - the
    same file the simulator reads - so base_plate, cam disc and comb positions fall
    out of cam_flat_z instead of being maintained by hand. This is the same
    duplicated-constant failure the CAD comments keep warning about. mid_plat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
    [electronics.js, export_glb.py]
2026-08-31 cam: blind bore, and the earlier bore fix only reached half the file
    TWO THINGS, and the second is a miss of mine.
    1. THE BORE IS BLIND AGAIN, as Mridul asked. A through-bore left the shaft 1.5mm
    proud of the cam face. It cleared the arms by 2mm so it was not a clash, but a
    shaft standing up through the surface the linkages run on is something to catch on
    during assembly, and it gave only 6mm of Double-D to carry the motor's torque
    through resin.
    A small boss on the disc centre takes the bore up without touching anything:
    shaft above its boss 7.5mm
    hub 4 + disc floor 2 6.0mm not enough alone
    + cap 2.6 less 0.5 roof 8.1mm enough, 0.6mm spare
    Cap height is bound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
    [braille_cam.scad, braille_cam.stl]
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2026-08-31 cad: bare ULN2003AN spec, and the dock magnets line up again
    The ULN2003 breakout does not fit the 44mm cell in any orientation, so the
    driver becomes a bare DIP-16 on cut perfboard. electronics_spec.scad now owns
    the chip, the board, the stacked heights and the one position in the box that
    clears both the motor cup and the corner bosses, with asserts on each gap.
    Also: the pod still had mag_z = 29 under a comment saying it matched the cell,
    which stopped being true when the stack dropped 14mm. The two dock faces were
    15.5mm apart. Both now derive from dock_mag_z in dock_interface.scad.
    [dock_interface.scad, electronics_spec.scad, esp32_pod_params.scad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]
2026-08-31 cam: R-07 - size each ramp from its own track, and a 0.5mm dot
    angular_ramp_fraction was a single 0.2 applied to every track, so each ramp got
    a fifth of a state's arc and the rest sat flat. That made the lift faces 62-73
    degrees, well past the 30 degree limit where a translating follower stops
    climbing and starts wedging.
    Two things were wrong. The flat a stop needs was being sized from foot_w, but
    foot_w is the width across the track - the follower is a roll, so along the
    direction of travel it is point contact and needs almost nothing. And one global
    fraction let the outer tracks hoard arc the inner ones needed.
    Each track now takes the widest ramp its own radius allows. With pin_lift a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
    [base_plate.stl, braille_cam.scad, braille_cam.stl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]
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2026-08-31 sim: follow v8.8 - stack up 2.5mm, and the pod magnets come back to the dock
    The tower grew with hub_h 4 -> 6.5, so cam_flat_z 31 -> 33.5 and both shells
    46.5. export_glb.py needed no edit beyond its comments: every offset is derived
    from braillix_params.json now, and the three it produces - base plate 29.5, cam
    disc 31.5, top plate 42.5 - match outer_box.scad and the handoff exactly.
    electronics.js still carried mag z 29, which dock_interface.scad has just called
    out as the bug it is: the cell dropped to 13.5 and the pod kept the old number,
    so the two magnet rings stood 15.5mm apart. Now 13.5, from dock_mag_z.
    Hall follows the base plate, 27.8 -> 30.3. Shaft stays 9.5 - the cut was
    rejec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
    [electronics.js, export_glb.py]
2026-08-31 sim: the driver is a bare ULN2003AN now, not the breakout
    electronics_spec.scad dropped the 35x32mm module and the simulator was still
    drawing it, standing on edge at x=29 - outside the box wall, with its loom
    ending in mid-air at a JST plug that no longer exists.
    What it draws instead is what the cell carries: a ULN2003AN in a DIP-16 socket
    on a 28x18mm scrap of perfboard, 11mm overall. The hole grid is drawn because
    it is what makes the part read as perfboard rather than a PCB.
    Placement: the spec calls elec_pcb_x=16.0 the board's mid-plane, but that
    reading puts the chip at x=7.3, inside the motor cup. Read as the assembly
    mid-plane it spans 10.50..21.50 against a gap of 9.75..22.10 - e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
    [electronics.js]
2026-09-01 mech: raise the stack 2.5mm instead of cutting the motor, and thicken the arms
    The shaft ended above the cam face and something had to give. Cutting 2.5mm off
    the shaft is irreversible and has to be repeated perfectly on every unit ever
    built, so the hub grows instead: hub_h 4 -> 6.5 and the whole tower above the
    disc translates up with it. Cell and pod are 46.5mm, still 11.5mm below what
    they were before the motor moved onto the box floor.
    It is 2.5mm rather than 2.0 on purpose. At 2.0 the bore is exactly as deep as
    the shaft is long, so any plus tolerance and the cam hangs on the shaft tip
    instead of seating on the boss, which tilts the disc. 2.5 keeps 0.5mm of air
    over the tip and 0.5mm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
    [base_interface_coupon.stl, base_plate.stl, braille_cam.scad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]
2026-09-01 mech: braille cell was twice as wide as a real one; arm thickening undone
    col_spacing was 4.8mm against a 2.34mm standard while rows were 2.6, so the cell
    measured 4.8 x 2.6. Braille dot pitch is square - a cell looks tall because it is
    two columns by three rows, not because the pitch is uneven - so a finger trained
    on braille would not have read this as a cell at all.
    Narrowing the columns to match the rows costs nothing. Every clearance in the dot
    cluster is set by the rows, which are closer: spring wall 0.40, arm gap 1.60,
    dome gap 1.10, all identical before and after. The arms do not crowd either,
    since each already points outward the way its dot sits. The cell is now a uniform
    1.111x e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
    [base_interface_coupon.stl, base_plate.stl, braille_cam.scad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]
2026-09-01 spec: 0.20mm spring wire, and it was too tight for its own nub
    Takes the electronics fork's finding (69d109f): six 0.3mm-wire springs load the
    cam with about 17N, roughly 87 mN*m against a 30 mN*m motor, so it cannot turn
    before lifting anything. Rate goes as wire diameter to the fourth, so 0.20mm
    cuts it about five times.
    It is not only a BOM number. spring_id derives from the wire diameter and is the
    bore the linkage nub travels through, so 0.30 wire gave a 1.40mm bore against a
    1.414mm nub diagonal - interfering by 0.014mm, small enough that it read as a
    rounding error and nobody caught it. 0.20 wire opens the bore to 1.60 and leaves
    0.19mm. The assert in linkage.scad now derives from sp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
    [dot_insert.stl, linkage.scad, linkage.stl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]
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2026-09-03 dock: size the pogo cutout to the connector that was actually bought
    The window was a guess made before the part existed and it was wrong in both
    axes - 10 x 8mm against a real body of 20 x 4. Twice too narrow, nearly twice
    too tall. It now comes off the manufacturer drawing: 20.4 x 4.4 window, two
    1.3mm screw pilots on the 23mm hole pitch, 3.5mm deep into a 4mm wall so an
    M1.6 self-tapper gets the whole thickness rather than the 1.8mm a flush recess
    would have left.
    The shell magnets stay. The connector has its own pair but they are sized to
    hold a watch cable, not two 68mm boxes. They do have to move outboard: at
    y=17.5 the teardrop clears the wider window by 1.36mm, where at 14 it ran 2.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
    [dock_interface.scad, esp32_pod_params.scad, esp32_pod_shell.scad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]
2026-09-03 dock: the pogo connector is surface-mount, so the window goes away
    Looking at the drawing properly: the mounting ears sit OUTSIDE the 20mm body on
    a 23mm pitch and the spring pins face outward, so the part bolts flat to the
    outside of the wall. Nothing has to pass through it except the five solder tails
    and their wires.
    That removes the print problem rather than working around it. A 20.4 x 4.4
    through-window would have been a 20.4mm unsupported bridge across its top, and
    FDM sags 0.3-0.5mm over that span against the 0.20mm of clearance a 4.0mm body
    leaves - the window would have closed up on the exact part it was cut for. What
    replaces it is a 13 x 4mm tail slot that sits entirely behind th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
    [dock_interface.scad, esp32_pod_shell.scad, esp32_pod_shell.stl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]
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2026-09-03 sim: the pogo connector is a real bought part now, not four floating pins
    dock_interface.scad took the 5P magnetic connector off the manufacturer drawing
    and mounted it from inside the wall. The simulator was still drawing the thing
    that predated owning the part: four loose spring pins hovering in a guessed
    10 x 8mm "receiver envelope" that was wrong in both axes - far too tall and
    about half wide enough.
    What it draws now is the part. A 27mm ear plate carrying the two mounting holes
    at 23mm pitch, a 20 x 4mm boss standing 2mm proud of it, five ways on 2.54, the
    connector's own two alignment magnets at 16mm pitch, and the solder tails out
    the back. Every number is read from dock_interface.s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
    [electronics.js]
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2026-09-03 sim: the connector's discs lay along it instead of through it
    Mridul spotted the magnets standing proud of the boss face. They were, by
    1.2mm, and so was every other round part of the connector.
    cyl() already sets rotation.x = PI/2 to stand its axis up on Z. Calling
    rotation.set() afterwards REPLACES that, and rotating a CylinderGeometry about
    Y leaves its axis on Y, where it started - so all six discs lay along the
    connector's length rather than through its thickness. A 3mm magnet then spans
    1.5mm either side of centre inside a 2mm boss and pokes out the front.
    This file already carried the warning, on the pins it replaced: "Setting
    rotation.x AND rotation.y compounded into a quarter-turn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
    [electronics.js]
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
